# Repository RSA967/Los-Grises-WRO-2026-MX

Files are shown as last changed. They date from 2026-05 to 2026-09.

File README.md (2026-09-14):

# Los-Grises-WRO-2026-MX

Official repository of Team Los Grises for the **Future Engineers - World Robot O1ympiad 2026**.
<div align="center">
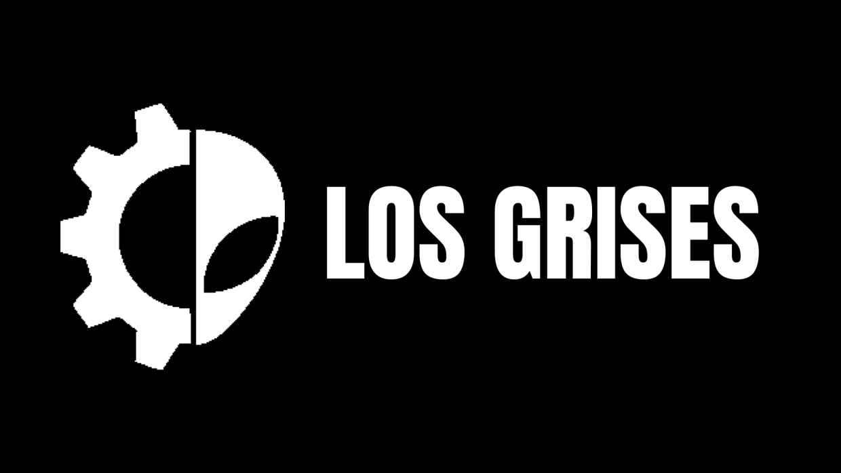
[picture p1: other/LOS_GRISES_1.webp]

</div>

## Robot Overview

Our robot follows a track using a steering servo and a DC drive motor. We use five ultrasonic sensors to measure wall distances, a BNO085 to track rotation, and an encoder to detect movement. For the Obstacle Challenge, an OpenMV camera also finds colored pillars and parking walls.

We have two programs for the ESP32, our main controller. In the **Open Challenge**, the robot follows the corridor, turns at corners and counts three laps before its final positioning maneuver. In the **Obstacle Challenge**, it passes red pillars on the right and green pillars on the left, then searches for the parking area after three laps.

Throughout this guide, motor percentages mean **PWM commands**, and servo angles mean **servo commands**. They are the settings we use to control motion, not measurements of road speed or wheel angle. Our recorded measurements are in [Testing and Calibration](#testing-and-calibration).

<!-- PENDING: confirm that the code, CAD, schematic and photographs correspond to the final competition robot. -->

## Robot Gallery

<table>
<tr>
  <th align="center">Front</th>
  <th align="center">Rear</th>
  <th align="center">Left</th>
</tr>

<tr>
  <td align="center" valign="middle">
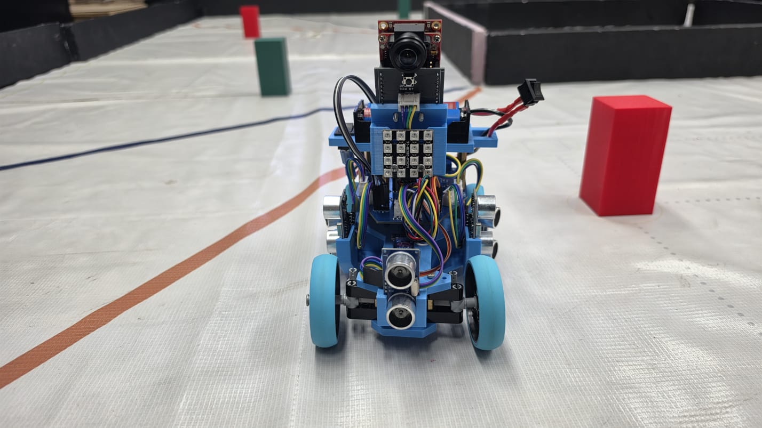
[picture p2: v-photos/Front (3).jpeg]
Robot front view
    
  </td>
  <td align="center" valign="middle">
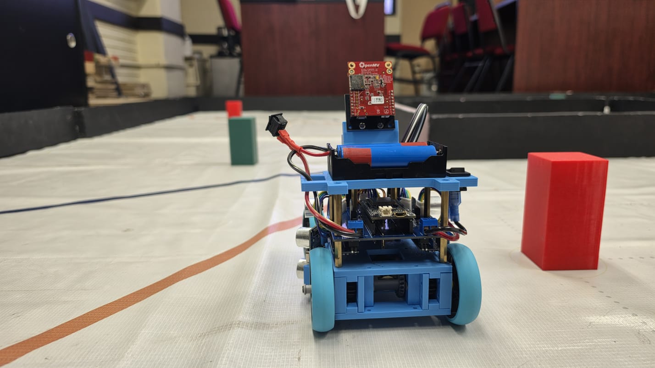
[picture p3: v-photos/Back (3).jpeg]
Robot rear view
    
  </td>
  <td align="center" valign="middle">
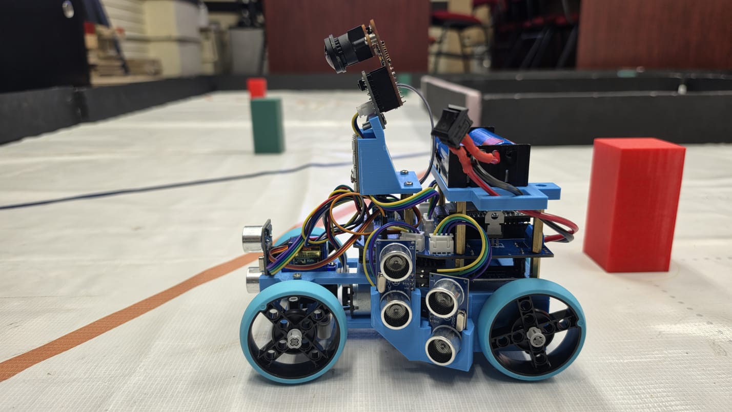
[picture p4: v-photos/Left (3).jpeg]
Robot left view
    
  </td>
</tr>

<tr>
  <th align="center">Right</th>
  <th align="center">Top</th>
  <th align="center">Bottom</th>
</tr>

<tr>
  <td align="center" valign="middle">
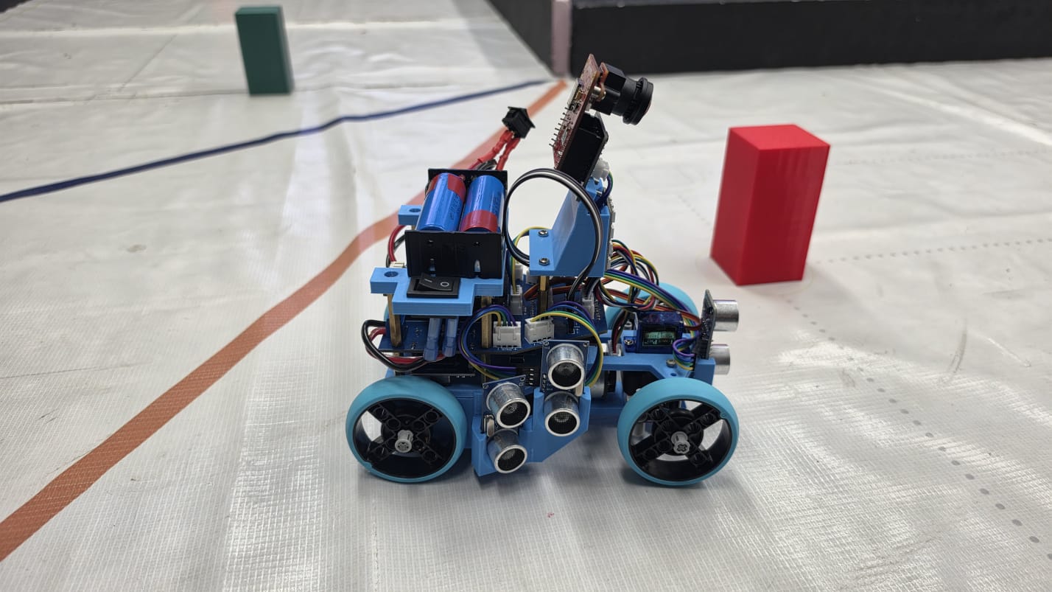
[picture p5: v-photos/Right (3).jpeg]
Robot right view
    
  </td>
  <td align="center" valign="middle">
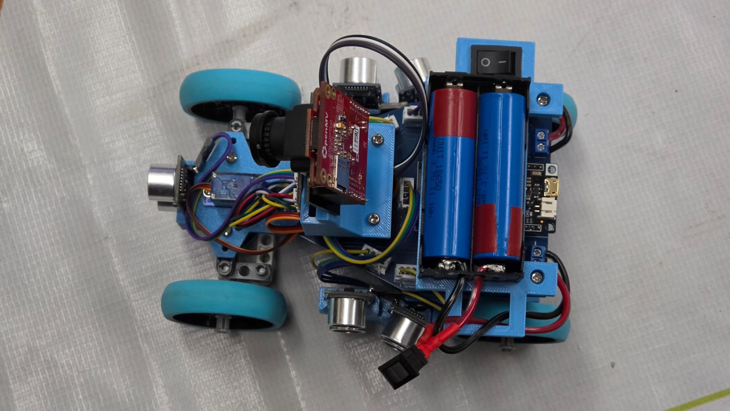
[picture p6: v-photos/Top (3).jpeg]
Robot top view
    
  </td>
  <td align="center" valign="middle">
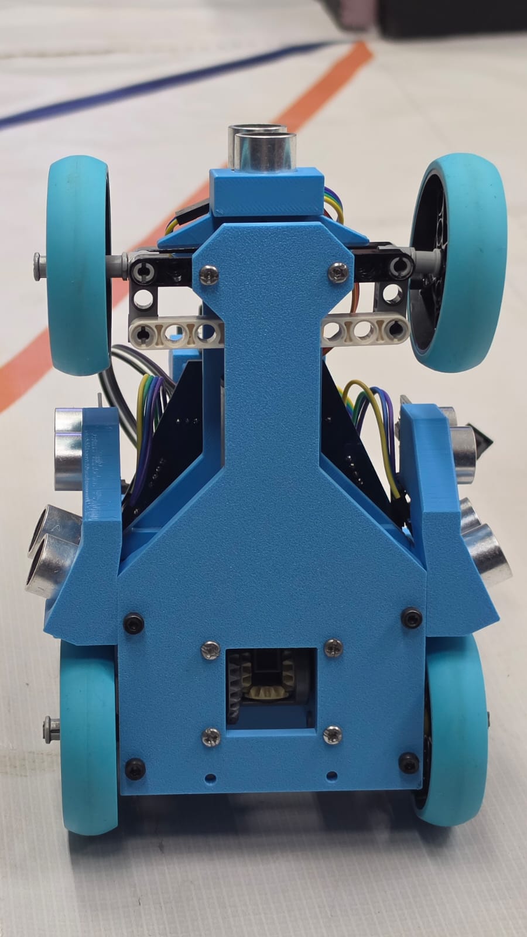
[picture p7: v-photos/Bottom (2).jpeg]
Robot bottom view
    
  </td>
</tr>
</table>

## Challenge Videos

### Open Challenge

<div align="center">

### 🧩 Driving Demonstration

</div>
<!-- PENDING: add a public or unlisted YouTube link showing at least 30 seconds of autonomous Open Challenge driving. -->

### Obstacle Challenge

<div align="center">

### 🧩 Driving Demonstration

</div>

<!-- PENDING: add a public or unlisted YouTube link showing at least 30 seconds of autonomous Obstacle Challenge driving. -->

## Mechanical Design

We control propulsion and steering separately. A DC motor provides drive through the TB6612FNG motor driver, while a servo moves the steering linkage. This lets us reverse the motor without changing how we command the steering. Our component list names a **GM25-370 6V 100RPM motor** and an **SG90 servo**; the voltage and speed in the motor name are part ratings.

The [3D model](https://github.com/RSA967/Los-Grises-WRO-2026-MX/raw/refs/heads/main/models/3D%20design%20of%20the%20robot%E2%80%94open%20in%20Onshape.3mf) contains the upper and lower bodies, a rear support, and left, right and central parts. It includes 24 mesh objects and uses **meters** as its unit. These shapes help show how the body and supports fit into the design.

We center the servo at **90°** and limit normal steering commands to **50–130°**. The challenge programs use different corrections within that range for following walls, turning corners and reversing.

<!-- PENDING: confirm final dimensions and weight; complete the steering-linkage/Ackermann geometry, driven-axle, wheel, transmission and assembly descriptions. -->

## Electronics and Power System

Our [electrical schematic], labelled **WRO 26 INDIA**, shows the FireBeetle ESP32 **DFR0478**, the Nano, camera, IMU and actuator connections. The TB6612FNG uses channel A for the drive motor. The ESP32 sends its speed command through PWM and selects direction through two digital signals.

The power circuit has an 18650 battery input, a switched **VM** branch for the motor, and Mini 560 buck-converter branches labelled **5+** and **3.3**. Separate 7805 regulator branches supply the servo and NeoPixel lighting. The drawing also shows common ground connections, a logic-level converter between 5 V and 3.3 V signal domains, and a **100 nF capacitor** across the motor terminals.

The [connection reference] gives the pin assignments and power-net details. Our [component inventory] includes tools and duplicate parts as well as robot components, so its quantities describe our inventory rather than the number fitted to one robot.

<!-- PENDING: confirm installed quantities and the BNO080/BNO085 module identity; reconcile the battery arrangement, final I2C/power wiring and PCB revision before completing the assembly instructions. -->

## Sensor Architecture

### Five HC-SR04 ultrasonic sensors

We place sensors on both sides and at the front. The side readings help us follow the corridor and finish passing pillars; the front sensor helps us slow down and detect a wall before reversing.

| Sensor | Position | Nano trigger / echo | Use in navigation |
|---|---|---|---|
| S1 | Left, 90° | D2 / D3 | Left corridor distance; red-pillar side confirmation |
| S2 | Left, 25° | D4 / D5 | Left corridor distance, Open corner detection and red-pillar confirmation |
| S3 | Front | D6 / D7 | Corner proximity, slowdown and front-wall escape |
| S4 | Right, 25° | D8 / D9 | Right corridor distance, Open corner detection and green-pillar confirmation |
| S5 | Right, 90° | D10 / D11 | Right corridor distance; green-pillar side confirmation |

The Nano reads **S3 → S1 → S5 → S2 → S4**. We check the front first, then alternate sides and leave a **10 ms delay** after each reading to space out the ultrasonic pulses. Each new distance becomes available immediately.

The Nano sends distances in millimeters over I²C at address **0x08**. The ESP32 requests ten bytes: two for each sensor, in S1-to-S5 order. It requests an update every 20 ms, using the latest reading from each sensor; the sensors are read sequentially, not all at once.

We limit the range to **2,000 mm**. A missing echo is also sent as 2,000 mm, so that value can mean either a clear path beyond the range or no echo. The [Nano program] contains the scan and message format.

### BNO085 and encoder

We use the BNO085's rotation-vector data to calculate **yaw**, the direction the robot is facing, and add up changes in rotation. We reject jumps greater than 90° between samples. This gives us the accumulated rotation used to count laps and guide Open's corner turns.

The encoder has A and B connections to **D5 and D9** on the ESP32. We count rising edges on channel A. In Open, these pulses confirm that the motor has started moving. In Obstacles, we also convert pulses to distance for collision recovery and parking.

The Obstacle program combines distance and heading into an X/Y position estimate. It uses the commanded motor direction for the sign of movement; channel B is not used to decode direction. This estimate does not directly steer the corridor controller.

### Camera and lighting

The **OpenMV H7 Plus** processes the image and sends object information to the ESP32. The Nano handles white NeoPixels on **D12** and receives brightness commands over I²C. Our Nano program is configured for **16 LEDs**.

## Software Architecture

The ESP32 brings the sensor information together and chooses the movement behavior. The Nano handles ultrasonic timing and lighting, while OpenMV handles image processing. This keeps their tasks separate from the main steering and drive logic.

```mermaid
flowchart LR
    US["Five HC-SR04 sensors"] -->|"Trigger / echo"| N["Arduino Nano"]
    N -->|"I2C: five distances"| E["ESP32: main controller"]
    E -->|"I2C: brightness"| N
    N -->|"D12"| LED["NeoPixel lighting"]
    CAM["OpenMV H7 Plus"] -->|"UART: vision data"| E
    E -->|"UART: parking mode"| CAM
    IMU["BNO085"] -->|"I2C: rotation vector"| E
    ENC["Motor encoder"] -->|"Movement pulses"| E
    E -->|"PWM"| SERVO["Steering servo"]
    E -->|"PWM and direction"| DRIVER["TB6612FNG"]
    DRIVER --> MOTOR["DC drive motor"]
```

The camera connections are used by the Obstacle program. Open follows the corridor without reading the camera. Power wiring and level conversion are shown in the schematic above.

| Controller / purpose | Source file |
|---|---|
| ESP32, Open Challenge | [ESP32_Open_Giro_90.ino](https://github.com/RSA967/Los-Grises-WRO-2026-MX/blob/main/src/ESP32_Open_Giro_90.ino) |
| ESP32, Obstacle Challenge | [ESP32_Obstaculos_V2.ino](https://github.com/RSA967/Los-Grises-WRO-2026-MX/blob/main/src/ESP32_Obstaculos_V2.ino) |
| Arduino Nano, sensors and lights | [Nano_Sensores_I2C__1_.ino](https://github.com/RSA967/Los-Grises-WRO-2026-MX/blob/main/src/Nano_Sensores_I2C__1_.ino) |
| OpenMV, vision | [color_corner.py](https://github.com/RSA967/Los-Grises-WRO-2026-MX/blob/main/src/color_corner.py) |

We load one challenge sketch on the ESP32 at a time. The two sketches stay in separate folders; they are not combined into a single program.

## Open Challenge Strategy

Our Open sequence is:

**Start → confirm movement → follow the corridor → detect and turn a corner → update the lap count → repeat → final positioning.**

### Starting and following the corridor

We begin with a **45% motor command** and wait for **four encoder pulses within a 600 ms detection window**. Once movement is confirmed, we start the round timer and a **five-second acceleration ramp**. This keeps the start tied to actual movement instead of just switching on the electronics.

To follow the corridor, we compare the left and right distance sums:

`error = (S1 + S2) - (S4 + S5)`

A **PID controller** turns that error into a steering correction. The proportional term responds to the current error, the integral term builds up while an error remains, and the derivative term responds to how quickly it changes. Our Open gains are **Kp = 0.04, Ki = 0.001, Kd = 0.003**. We limit the integral contribution and filter the derivative so that they do not produce excessive corrections.

Steering starts with a reduced proportional gain. As a front or side wall gets closer, we increase the response and reduce the motor target. The normal target is **100%**, reducing toward **60%** near walls. Front-distance slowdown grows between **600 and 200 mm**. When front and side protection both request a slowdown, we use the lower target.

### Detecting and turning corners

We look for a change from a nearby wall to an opening at S2 or S4. A reading of **800 mm or less** arms that side. A later reading of **at least 1,250 mm**, while S3 is still at **800 mm or less**, becomes a corner candidate. We require three confirming polls before turning.

During the turn, we use the BNO085 to track a **90° change in rotation**, with a 2° completion tolerance. The steering correction is **35°** and the motor command is **55%**. We then center the servo briefly before returning to corridor PID. Once a course direction has been chosen, later corner detections follow that direction.

If a turn has not finished after **2.5 seconds**, or valid heading is lost during the turn, the robot stops rather than continuing the turn indefinitely.

### Front-wall protection and recovery

If **S3 reaches 150 mm or less**, we cut drive, center the steering and brake before reversing at **45%**. We keep steering centered during this escape and resume forward control when S3 reaches **250 mm**. If reverse motion does not clear the wall within **2.5 seconds**, the robot stops and waits.

The general distance-data timeout is **250 ms**. Heading-loss behavior depends on the current maneuver: a 90° turn and final heading adjustment have their own stop conditions. The current setting allows ordinary corridor movement without heading, so an IMU failure is not a universal motor stop.

### Counting laps and final positioning

After encoder-confirmed startup, we accumulate the BNO085's rotation. Each 360° contributes one lap; at **1,080° of absolute accumulated turn**, we begin final positioning. This is our internal lap counter, based on rotation rather than detection of every field section.

We keep normal control for **500 ms of effective commanded forward motion**. Braking and reverse-escape pauses do not count toward this interval. Then, if S3 is below **1,000 mm**, we reverse at **35%** while correcting heading toward ±1,080°. The adjustment ends at **1,100 mm** of front clearance, after a **five-second limit**, or on the relevant sensor failure. If no adjustment is needed, the robot stops directly.

## Obstacle Challenge Strategy

For this challenge, we follow the corridor until the camera finds a pillar. We guide the robot past it on the correct side, use the side sensors to finish the pass, and return to corridor control. After three accumulated laps, we switch to searching for the parking area.

### Passing on the correct side

- **Red pillar, ID 5:** pass on the right, leaving the pillar on our left.
- **Green pillar, ID 3:** pass on the left, leaving the pillar on our right.

We use corridor PID between pillars, with **Kp = 0.12, Ki = 0.0015, Kd = 0.006**. The normal motor target is **70%**, reducing toward **50%** near corners. The IMU counts rotation and supports the position estimate and parking-side choice; it does not directly steer this corridor PID.

### Camera control and pillar lock

When the camera finds a valid target, we **lock its color ID**. This keeps a passing maneuver focused on one pillar instead of switching targets with every image. The upper image region guides the approach. In the lower region, we increase the passing offset as the pillar appears closer to the bottom of the image.

When the robot gets very close, the pillar can leave the camera's view. After the locked pillar reaches the low ROI, we use the side ultrasonics to confirm it alongside the robot: **S1/S2 for red**, and **S4/S5 for green**. A distance of **300 mm or less** in two polls starts the final part of the pass, with a **20° wrap correction** and **35% motor target**.

We release the lock after both sensors on that side report at least **360 mm**, with repeated confirmation and a short clear hold. The wrap also has a time limit, because a wall beside the robot might never give a clear reading. If the old target disappears and a new color is repeatedly detected, the lock can switch to the new pillar.

We return steering gradually to the corridor target, at up to **45° per second**. When a front wall is close, corridor control takes over immediately so that a smooth transition does not delay a needed turn.

### Wall protection and collision recovery

While the camera is steering, a side-wall limiter reduces only the correction that points **toward** a close wall. It works between **300 and 130 mm**, cancelling steering toward that side at 130 mm and limiting the motor target to **45%**. This protects wall clearance, but also leaves less room to go around a pillar.

The front guard adds more steering correction when a pillar is close to a front wall. If S3 reaches **150 mm**, front-wall escape takes priority: we brake, center the servo and reverse until there is **250 mm** of clearance or the escape times out.

We also check whether the locked pillar's image enters the collision region. After **two confirming frames**, we brake and reverse **100 mm at 30%**, using encoder pulses to measure that distance. If the distance is not reached within **1.5 seconds**, we stop anyway. We wait for **three clear frames** before another attempt. This collision indication comes from the camera, not a contact switch.

During forward navigation, wall escape has priority over pillar tracking, followed by collision recovery and the normal camera/corridor behaviors. Parking entry uses its own sequence and limits, described below.

If camera data stops arriving for **500 ms** after communication has started, we release the pillar lock and return toward corridor control. Wall following can continue, but without current vision we cannot rely on the pillar-passing strategy.

## Computer Vision

We use OpenMV to find **red and green pillars**, **parking walls** and a small central sample of the black wall. It processes **320 × 240 RGB565 images** and sends detections to the ESP32 rather than sending full images.

### Color and shape

We find connected color regions, called **blobs**, using LAB thresholds. L represents lightness; A and B represent color axes. These are our active pillar ranges:

| Color | L min / max | A min / max | B min / max |
|---|---|---|---|
| Red | 20 / 55 | 31 / 71 | −19 / 43 |
| Green | 32 / 68 | −128 / −16 | −128 / 127 |

Color alone is not enough. Floor markings can also enter these ranges, so we check shape and how much of the bounding box is filled. A pillar must be taller than it is wide, with a height/width ratio of at least **1.20**, and fill at least **60%** of its box. We also check size and rotation.

Red and magenta overlapped under artificial light, so we use the red-range candidates for parking walls too, then separate them by shape. A wall must be wide, with width/height of at least **1.30**. We reject candidates cut by the top of the parking search region because a cropped pillar can look short and wide. The separate magenta thresholds are not active in this detection path.

### Regions of interest and object position

A **region of interest (ROI)** tells us which part of the image to use for a particular task.

| Region | `(x, y, width, height)` | Purpose |
|---|---|---|
| High | `(90, 100, 140, 40)` | Guide the approach to a pillar |
| Low | `(0, 140, 320, 100)` | Guide the close pass |
| Collision | `(120, 200, 80, 15)` | Check whether the selected reference corner enters the collision zone |
| Parking search | `(0, 70, 320, 170)` | Find wide wall shapes |

We track the **bottom-left corner of green pillars** and the **bottom-right corner of red pillars**. We normalize X to **−100…100**, while Y stays in pixels. Using the same reference corner in both high and low regions keeps the coordinate meaning consistent during the approach. These are image positions, not measured distances in millimeters.

If both colors are present, the camera selects the larger-area candidate, choosing green on a tie. The small central black-wall sample is reported for display; we do not use it to trigger turns.

### Communication and lighting

The camera sends ten comma-separated integers and a newline over **UART at 19,200 baud, 8N1**:

```text
ID,X,Y,AREA,ROI,COLLISION,BLACK_WALL,PARKING_VISIBLE,PARKING_X,PARKING_AREA
```

The ESP32 can send `P,1` or `P,0` to control parking detection. We currently keep detection enabled throughout the run, while the driving sequence waits until three laps to begin parking. The optional path-preview telemetry and overlay are disabled.

At camera startup, we allow a short automatic adjustment, then lock gain and white balance and use **30,000 µs exposure**. In Obstacles, near, far and parking brightness are all **50%**, keeping the light target the same as the robot changes tasks. Open starts with a 0% base and uses a 20% corner indicator.

## Parking Strategy

After three accumulated laps, we search for the parking walls, move alongside the gap and reverse into it in two stages. We use a **state machine** so that each stage has a clear job and a condition for moving to the next one.

```mermaid
stateDiagram-v2
    [*] --> SEARCH: three laps
    SEARCH --> PASSING: wall visible or already passed
    PASSING --> ALIGNING: two walls passed
    ALIGNING --> BRAKING: distance or side clearance or phase timeout
    BRAKING --> REVERSE_TURN: 250 ms
    REVERSE_TURN --> REVERSE_STRAIGHT: 240 mm or phase timeout
    REVERSE_STRAIGHT --> DONE: 150 mm or phase timeout
    DONE --> [*]
```

- **SEARCH:** follow the corridor with a **50% speed cap** and a **10° steering bias** toward the parking side. The bias brings us closer to the side where we are looking for the gap.
- **PASSING:** reduce the cap to **45%** and count two walls. We require repeated visible and absent frames so that one flickering detection does not count as a wall passed.
- **ALIGNING:** advance **260 mm by encoder**, or until the side sensors confirm at least **300 mm** of clearance. A phase timeout also ends this advance, but we only continue into reverse if the parking side is known.
- **BRAKING:** stop for **250 ms** and preposition the steering.
- **REVERSE_TURN:** reverse at **32%**, using a **34° steering correction** with its sign chosen for the parking side, for **240 mm**.
- **REVERSE_STRAIGHT:** countersteer with a **26° correction**, still at **32%**, for **150 mm** to straighten the robot. The servo is not centered during this stage.
- **DONE:** stop the motor and center steering. The robot stays stopped.

At the start of parking, accumulated yaw normally selects the side: positive rotation is configured as counterclockwise and selects the right; negative selects the left. Camera X supplies a side only if one has not already been assigned. While parking, camera messages count walls without starting new pillar-lock or visual-collision actions.

Each reverse stage has a **six-second limit** as an alternative to its distance target. The whole sequence has a **70-second limit**, and **1.5 seconds without Nano data** aborts it. We have no rear-distance sensor, so we bound reverse motion with encoder distance and time. The ordinary 250 ms distance timeout is replaced by the parking timeout, and front-wall escape is suppressed during braking and reverse entry.

Reaching `DONE` means that the movement sequence ended, which can also happen after a phase timeout. It does not measure whether the robot is fully inside the bay and parallel to the wall; those are the checks needed when observing a parking attempt.

## Engineering Decisions and Improvements

Our control decisions connect the sensing and movement tasks. A smoother steering change is not always the best choice near a wall, and a newer camera reading can be more useful than processing every queued frame. The following choices explain how we handle these situations. More detail is in our [Engineering Journal]

### Giving ultrasonic readings time and keeping I²C responsive

We read the ultrasonics sequentially and alternate sides to space out their pulses. Publishing each result immediately lets the ESP32 use it without waiting for the other four sensors. The trade-off is that the five distances come from slightly different times.

For Obstacles, we reduced I²C from **100 to 50 kHz** to give the signals more settling time in the presence of electrical noise. Open remains at 100 kHz. We also limit I²C waiting and reinitialize the bus when the Nano stops responding. Slowing communication and retrying it are separate measures: one changes normal timing, while the other addresses a stalled connection.

### Staying with a pillar without following an old target

The pillar lock solves one problem but can create another: holding the old color too long can keep steering toward a pillar we have already passed. We combine the camera-to-ultrasonic handoff with side-clearance checks and time limits, and allow a repeatedly detected new color to replace a stale target. This balances finishing one pass with responding to the next pillar.

### Balancing smooth steering and wall clearance

We use a gradual return to corridor PID on clear sections, but allow an immediate return near a front wall. Smooth steering is useful until it delays a turn that needs to happen now.

A fixed **8°** front-guard correction was too small in a corner, so we changed it to grow from **8° to 20°** as the front distance decreases. The side-wall limiter handles a separate compromise: keeping farther from the wall can leave less clearance around the pillar.

### Tying motion to encoder pulses

We use encoder pulses to confirm startup before beginning the acceleration ramp. In Obstacles, we also cap startup output at the requested target: a behavior asking for 30% should not receive the 45% startup command.

For collision recovery, we reverse by a measured pulse count corresponding to **100 mm** and add a time limit in case the distance is not reached. The same pulse-to-distance conversion supports parking. This connects our encoder calibration to the maneuvers that need distance information.

### Recovering sensors and discarding old images

An IMU that fails to initialize should not be ignored for the rest of the run. The Obstacle program retries before and after the round timer starts, with longer intervals after startup because initialization can interrupt normal control. It also reinitializes after a prolonged loss of rotation data.

Camera messages can queue up while the ESP32 is busy. Steering from an old image would point toward an outdated pillar position, so we discard excess backlog and process a limited number of complete messages per loop. This leaves time for distance readings and steering updates, at the cost of skipping some camera frames.

### Using shape and steady lighting

When red and magenta overlapped under artificial light, we separated tall pillars from wide walls instead of relying only on color. We also lowered the wall width/height threshold from **1.50 to 1.30** because an oblique wall could fall close to the old limit.

An exposure of **10,000 µs** made the image too dark, so we use **30,000 µs**. We keep the same 50% lighting target through obstacle driving and parking, avoiding a light-target change just when the camera begins a different task.

## Testing and Calibration

### Encoder distance calibration

Our encoder calibration notes record two trials over one meter:

| Trial / calculation | Result |
|---|---|
| Test 1, 1 meter | **3,870 pulses** |
| Test 2, 1 meter | **3,988 pulses** |
| Average | **3,929 pulses/m** |
| Conversion | `1000.0 / 3929.0` ≈ **0.2545 mm/pulse** |

We multiply the pulse count by this conversion in the Obstacle program to calculate collision-recovery and parking distances. It also feeds the position estimate. Open uses pulses to confirm startup, without applying this distance conversion.

### Camera observations

Our vision notes describe parking-wall width/height ratios of approximately **2.0 front-on** and **1.5 at an oblique angle**. This explains the change to a 1.30 wall threshold. They also compare a solid pillar filling roughly **85% or more** of its box with a diagonal floor marking around **45%**, which supports using a density filter. These are approximate observations, not a detection-accuracy score.

PID gains, LAB thresholds and maneuver limits are settings, not experimental results. The [calibration record](tests/calibration.md) keeps the measurement notes and the separate track-time estimate together, with their context.

<!-- PENDING: add final-version Open and Obstacle run records or videos, including observed parking containment, alignment and contact with bay markers. -->

## CAD, PCB and Manufacturing

Use these files to inspect the mechanical parts, follow the connections and understand the board layout:

| Asset | Use |
|---|---|
| [Part Studio 1.3mf](https://github.com/RSA967/Los-Grises-WRO-2026-MX/raw/refs/heads/main/models/3D%20design%20of%20the%20robot%E2%80%94open%20in%20Onshape.3mf) | View the 24 mesh objects for the body and supports. Check that the viewer respects the meter units. |
| [Electrical schematic](https://github.com/RSA967/Los-Grises-WRO-2026-MX/blob/main/models/Layout%20of%20the%20Printed%20Circuit%20Board%20(PCB)%20Components.jpeg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) | Follow controller, sensor, actuator and power connections. |
| [PCB layout](https://github.com/RSA967/Los-Grises-WRO-2026-MX/blob/main/models/(PCB).jpeg?raw=true) | View tracks, connectors and component footprints. |
| [Fabricated PCB photo](https://github.com/RSA967/Los-Grises-WRO-2026-MX/blob/main/models/Layout%20of%20the%20Printed%20Circuit%20Board%20(PCB)%20Components.jpeg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) | See the unpopulated board before components are fitted. |
| [Component inventory](https://github.com/RSA967/Los-Grises-WRO-2026-MX/raw/refs/heads/main/models/Tabla_de_componentes_robotica.docx) | Identify part names and view component photographs. |

The PCB files here are images for reading the layout and connections. Manufacturing a matching board requires the editable design and fabrication outputs. The 3MF contains part meshes rather than a parametric CAD history.

<div align="center">
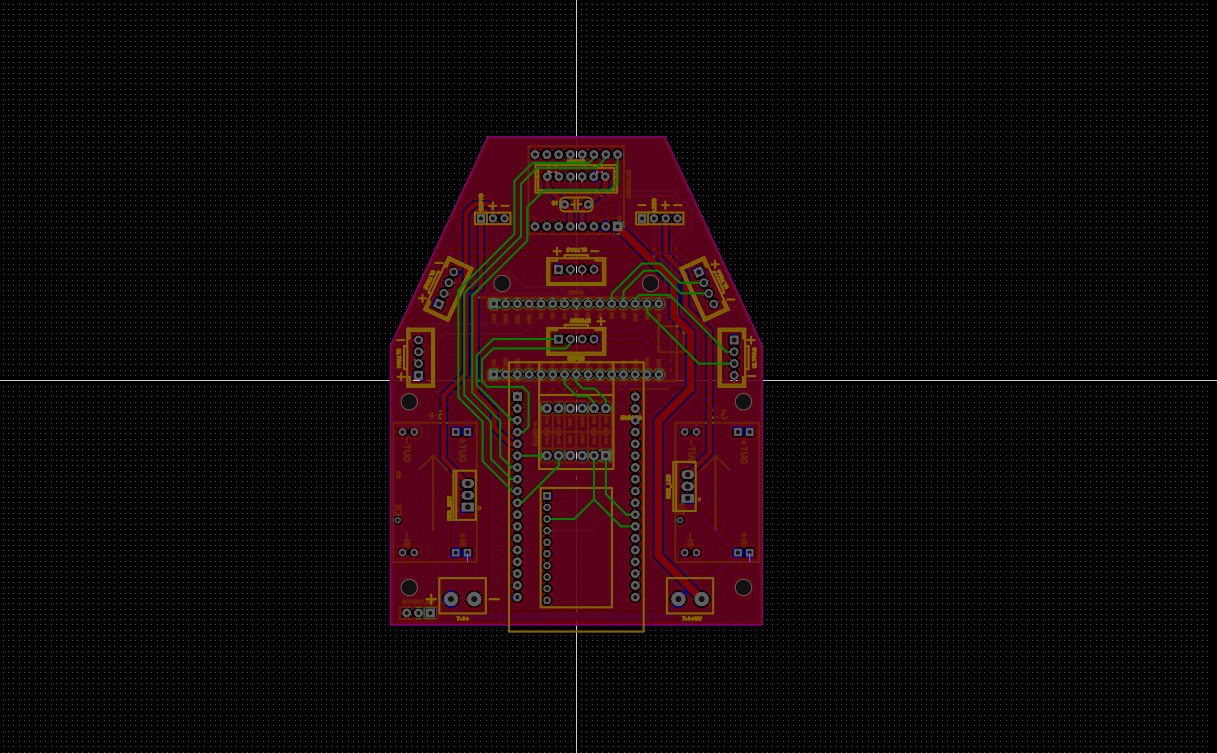
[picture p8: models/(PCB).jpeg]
</div>

<div align="center">
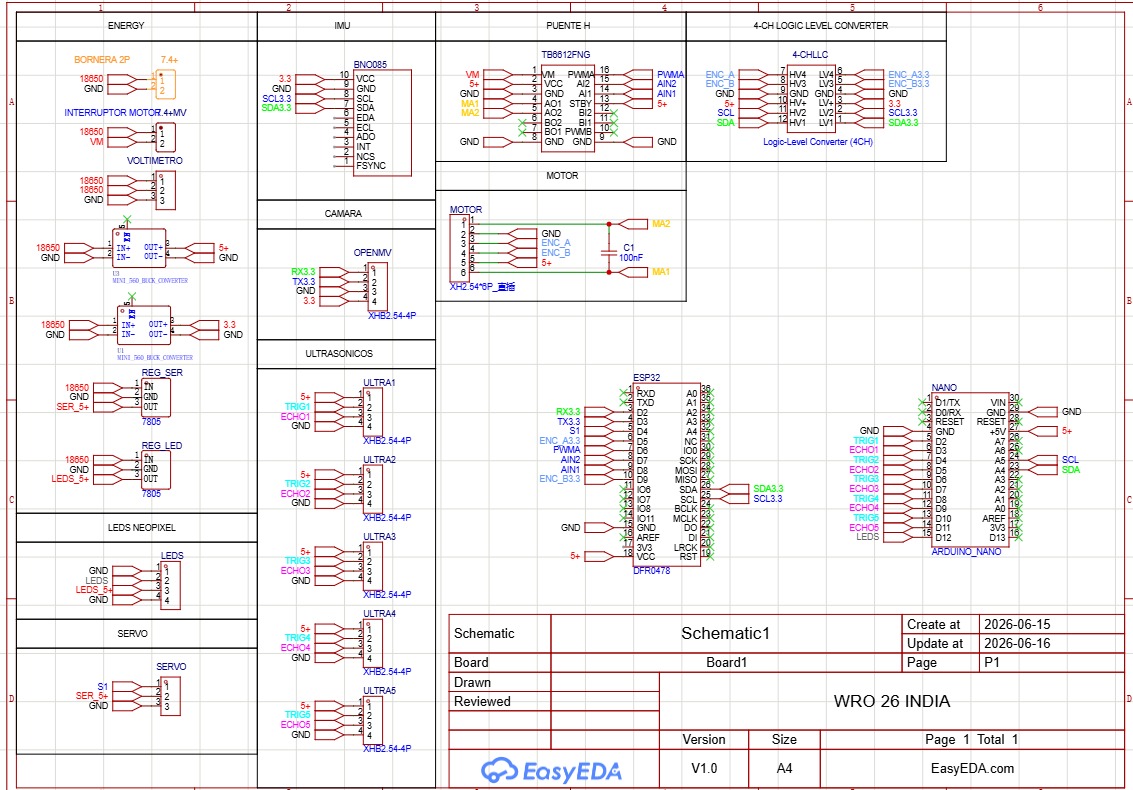
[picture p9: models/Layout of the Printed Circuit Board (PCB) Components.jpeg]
</div>

<!-- PENDING: add the PCB fabrication outputs and assembly instructions needed to reproduce the final mechanical and electronic build. -->

## Repository Structure

The main robot files and technical guides are organized as follows:

```text
README.md
code/
  ESP32_Open_Giro_90/ESP32_Open_Giro_90.ino
  ESP32_Obstaculos_V2/ESP32_Obstaculos_V2.ino
  Nano_Sensores_I2C__1_/Nano_Sensores_I2C__1_.ino
  openmv/color_corner.py
cad/Part Studio 1.3mf
pcb/layout.jpg
wiring/schematic.jpg
images/pcb-fabricated.jpeg
tests/calibration.md
docs/
  electronics.md
  engineering-journal.md
  components-original.docx
  references/
    future-engineers-2026-rules-es.pdf
    future-engineers-2026-rubric-es.pdf
```

## How to Reproduce the Robot

### Hardware and connections

Start with the [3D model], [schematic], [component inventory] and [pin reference]. The model shows part geometry; the pin reference covers the five sensor pairs, motor driver, servo, encoder, I²C and camera UART. The inventory also contains duplicate parts and workshop tools.

### Programs and dependencies

Open the `.ino` file inside its matching sketch folder and select the challenge program for the ESP32. Upload the Nano sketch to the Nano separately. The ESP32 pin aliases follow the **FireBeetle DFR0478** layout, so the board definition matters when resolving names such as `D5` and `D6`.

The ESP32 sketches use `Wire`, `Adafruit_BNO08x`, `WiFi`, `WebServer` and `esp_arduino_version`. The Nano sketch uses `Wire` and `Adafruit_NeoPixel`. The ESP32 PWM setup contains separate branches for board-package versions below 3 and versions 3 or above.

Run `color_corner.py` on the OpenMV camera. It uses `sensor`, `time`, `micropython`, `machine.UART` and `binascii`/`ubinascii`, so it needs the OpenMV environment rather than desktop Python. Camera UART3 runs at **19,200 baud**; the ESP32 side uses **RX GPIO25 and TX GPIO26**.

### Preparing and checking the system

Before a run, use the sensor layout and calibration values in this guide to check the steering center, encoder conversion and camera settings against the hardware. The Nano should respond at **0x08** with ten bytes, and OpenMV should send the ten-field message described above.

The ESP32 serial monitor runs at **115,200 baud** and reports distances, movement states and faults. In Open, the electronics can stay powered while the motor-power switch is open; movement confirmation starts when encoder pulses arrive.

The dashboards are enabled in the current sketches for testing. For competition rounds, Wi-Fi must be disabled as required by the rules. The code has a dashboard-off setting that switches off Wi-Fi; the competition configuration still needs to be selected and checked before a run.

<!-- PENDING: record the tested board definitions, library/OpenMV firmware versions, exact upload and persistent startup steps, and confirm the final competition configuration with wireless disabled. -->
<!-- PENDING: confirm the submitted repository URL, required historical commits, event deadline and final version notes before submission. -->

|COMPONENT| DESCRIPTION | IMAGE | PURCHASE LINK|
|---|---|---|---|
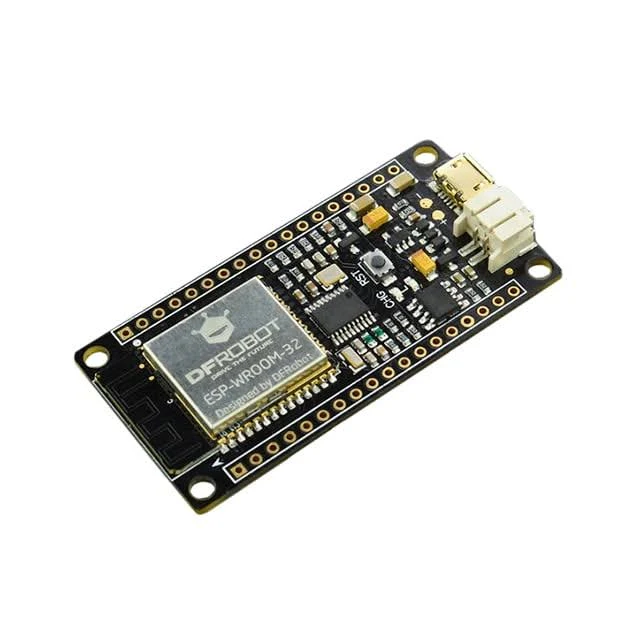
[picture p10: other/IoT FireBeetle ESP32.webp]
|IoT FireBeetle ESP32|FireBeetle ESP32: IoT board with Wi-Fi, Bluetooth, a lithium battery charging chip, and ultra-low power consumption (10 µA in standby mode).|  |[Buy here](https://www.amazon.com.mx/UEYGHEP-FireBeetle-Development-Bluetooth-habilitado/dp/B0GFDXH1XS)|
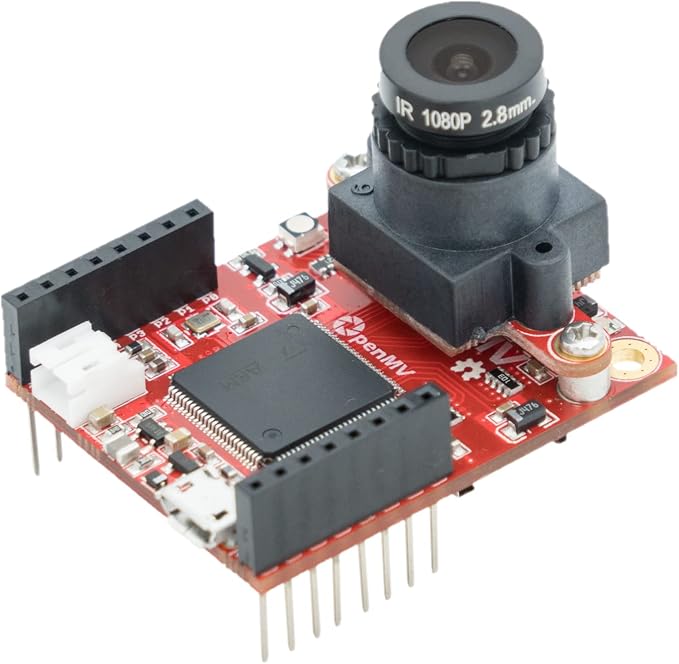
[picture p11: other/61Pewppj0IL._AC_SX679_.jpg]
|Genuine OpenMV CAM H7 Plus / OpenMV4 CAM H7 Plus, 5MP|OpenMV H7 Plus: A 5 MP camera programmable in MicroPython for computer vision and AI (TensorFlow Lite), featuring a 480 MHz processor, 32 MB of SDRAM, and UART/I2C/SPI outputs for robotics.|  |[Buy here](https://www.amazon.com.mx/OpenMV-SingTown-Processing-Robotics-Detection/dp/B09WYQR6XH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)|
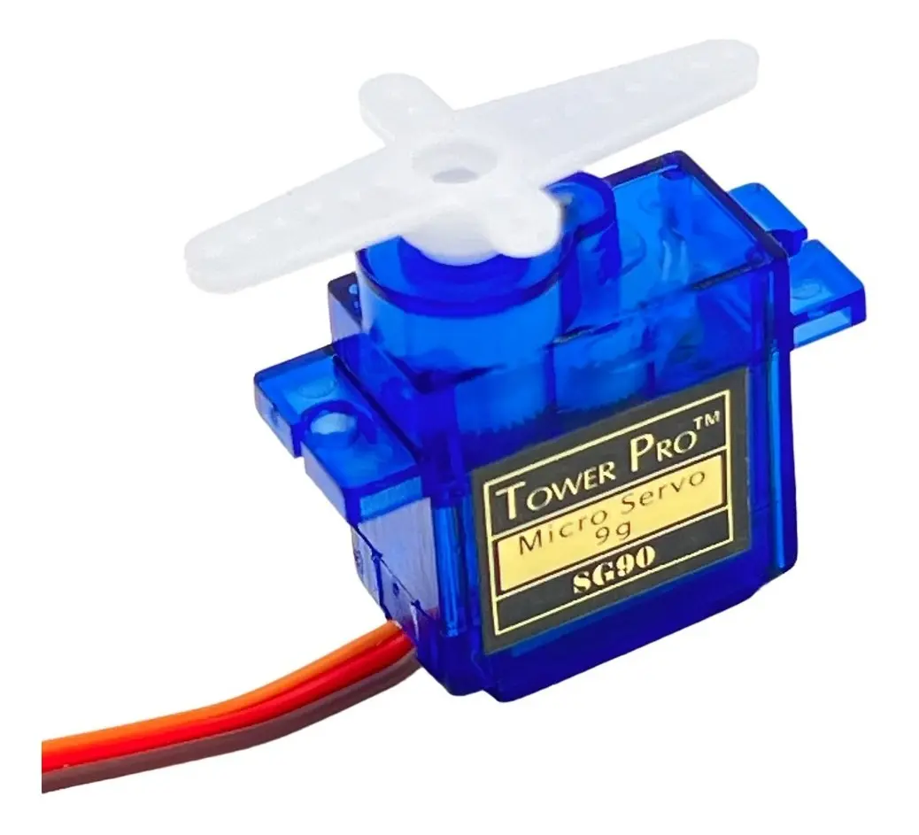
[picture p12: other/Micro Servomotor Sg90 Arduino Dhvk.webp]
|Micro SG90 9G Servomotor|SG90 Servo (9g): Compact, PWM-controlled actuator with a 180^\circ range, 1.8 kg·cm of torque at 5V, and plastic gears—ideal for lightweight robotics.|  |[Buy here](https://www.mercadolibre.com.mx/micro-servomotor-sg90-arduino-dhvk/p/MLM2072764647)|
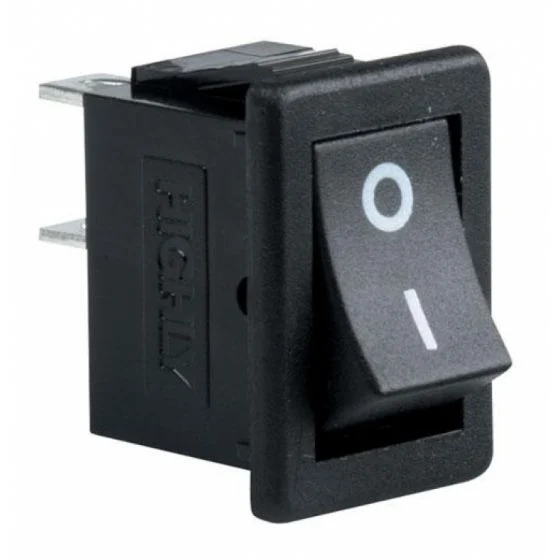
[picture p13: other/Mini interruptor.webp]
|Mini Switch|Compact mechanical on/off (ON/OFF) or circuit-switching switch, ideal for controlling power or signals in electronics and robotics projects.|  |[Buy here](https://www.steren.com.mx/switch-miniatura-de-balancin-de-1-polo-1-tiro-2-posiciones.html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)|
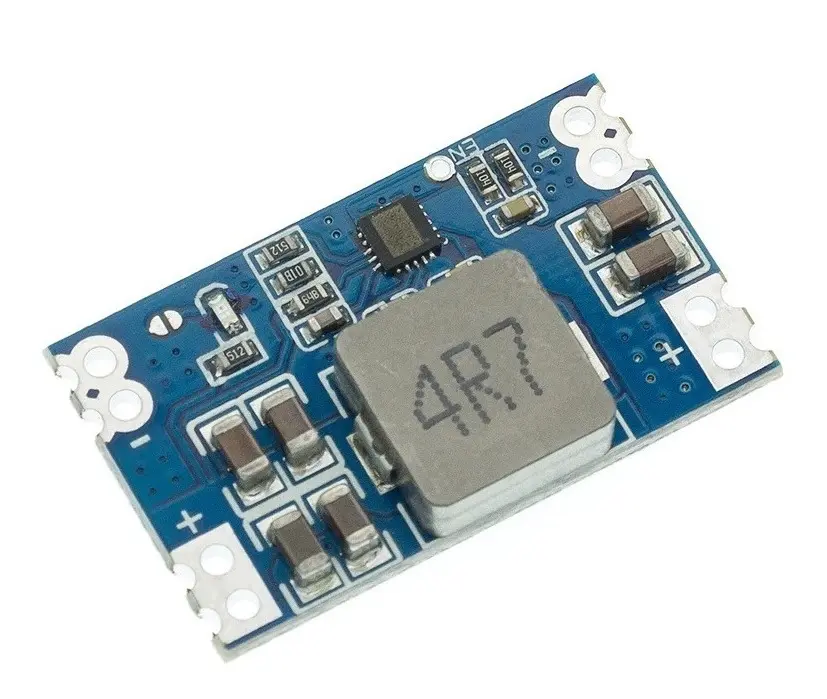
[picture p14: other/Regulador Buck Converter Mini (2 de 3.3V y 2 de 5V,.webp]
|Mini Buck Converter (2 x 3.3V and 2 x 5V, |A compact step-down voltage regulator module that converts higher input voltages (6V–20V) into two 3.3V and two 5V fixed outputs simultaneously to power microcontrollers and sensors.|  |[Buy here](https://www.mercadolibre.com.mx/mini560-regulador-step-down-buck-520v-a-33v-5a/up/MLMU801699768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)|
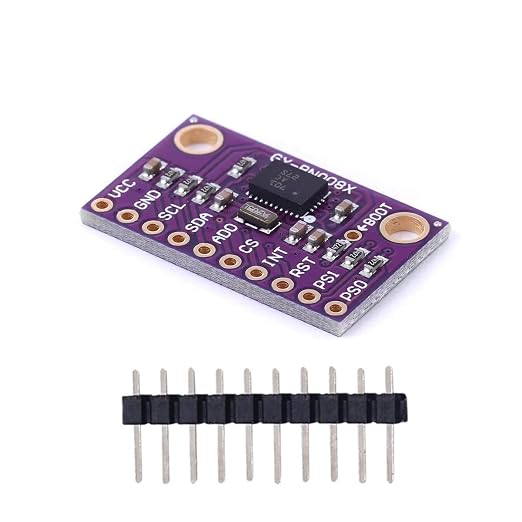
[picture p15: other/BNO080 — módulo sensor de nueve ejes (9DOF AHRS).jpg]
|BNO080 — Nine-Axis Sensor Module (9DOF AHRS)|Nine-axis sensor module combining a 3-axis accelerometer, 3-axis gyroscope, and 3-axis magnetometer with an onboard ARM Cortex-M0+ running Hillcrest's SH-2 firmware. It performs onboard sensor fusion to output precise 3D orientation (quaternions, Euler angles) over I2C, SPI, or UART without burdening the main microcontroller.|  |[Buy here](https://www.amazon.com.mx/MerciL-BNO080-BNO085-Aceler%C3%B3metro-Magnet%C3%B3metro/dp/B0D676S54D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)|
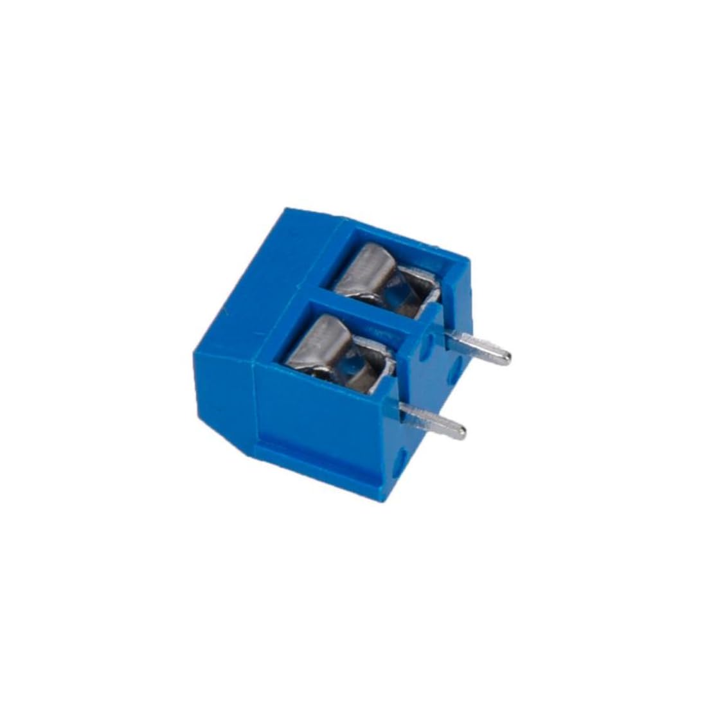
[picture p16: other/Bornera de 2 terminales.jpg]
|2-terminal terminal block|A screw or push-in connector module that allows secure, detachable wiring connections between power sources or components and a circuit board without soldering.|  |[Buy here](https://www.amazon.com.mx/BORNERA-CULCA-CLEMA-PAQUETE-PIEZAS/dp/B08MLGXP52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)|
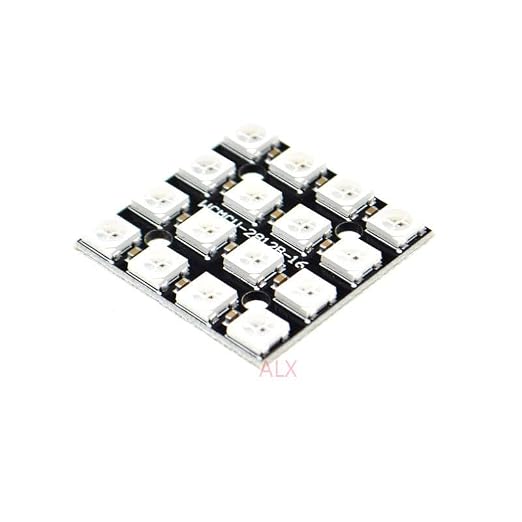
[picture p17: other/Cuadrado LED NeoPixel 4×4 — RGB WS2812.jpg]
|4×4 NeoPixel LED Square — RGB WS2812|A compact matrix of 16 individually addressable RGB LEDs that can display over 16 million colors using a single microcontroller data pin.|  |[Buy here](https://www.amazon.com.mx/bits-WS2812B-5050-M%C3%B3dulo-color/dp/B09T5XJP69)|
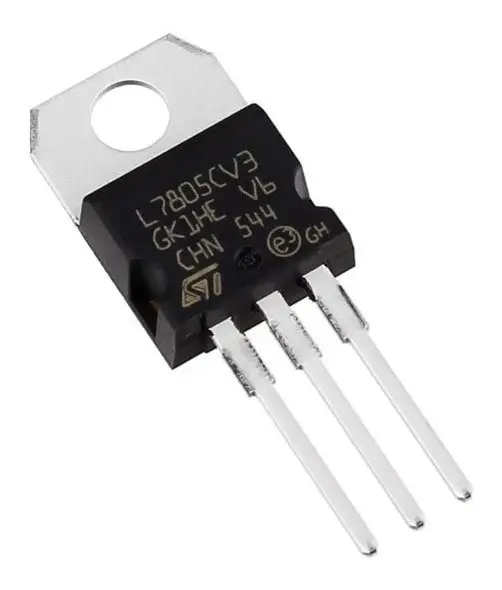
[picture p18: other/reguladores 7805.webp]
|7805 regulators|A linear regulator that steps down higher DC input voltages (7V–35V) to a stable, fixed 5V output at up to 1.5A.|  |[Buy here](https://www.mercadolibre.com.mx/50-pzs--7805--l7805-regulador-voltaje-5-volts/up/MLMU974457952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)|
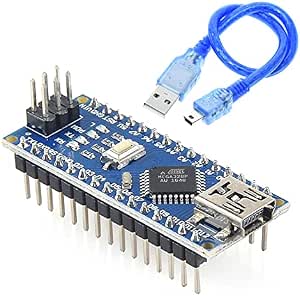
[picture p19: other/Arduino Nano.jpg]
OpenMV Cam[ H7 Plus
|Arduino Nano|A compact, breadboard-friendly microcontroller board based on the ATmega328P, running at 16 MHz with 32 KB Flash memory and an integrated USB port for easy programming.|  |[Buy here](https://www.amazon.com.mx/UNIT-ELECTRONICS-Cable-Compatible-Arduino/dp/B09MRFHR9C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)|
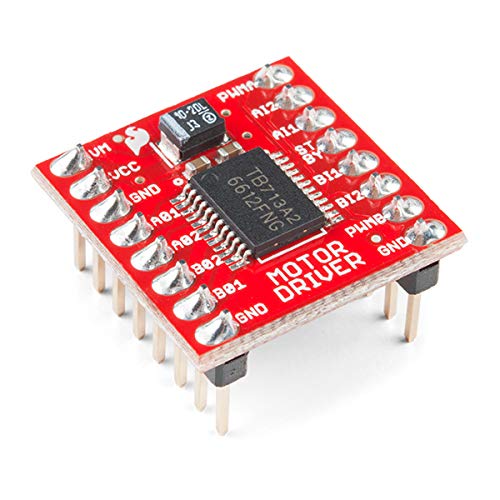
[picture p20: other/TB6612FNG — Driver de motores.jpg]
|TB6612FNG — Motor Driver|A dual H-bridge motor driver IC that can independently control speed (via PWM) and direction for two DC motors (up to 1.2A continuous per channel, 3.2A peak) or one stepper motor, offering high efficiency over traditional L298N drivers.|  |[Buy here](https://www.amazon.com.mx/SparkFun-TB6612FNG-driver-motor-cabezales/dp/B07PV1S8HX)|
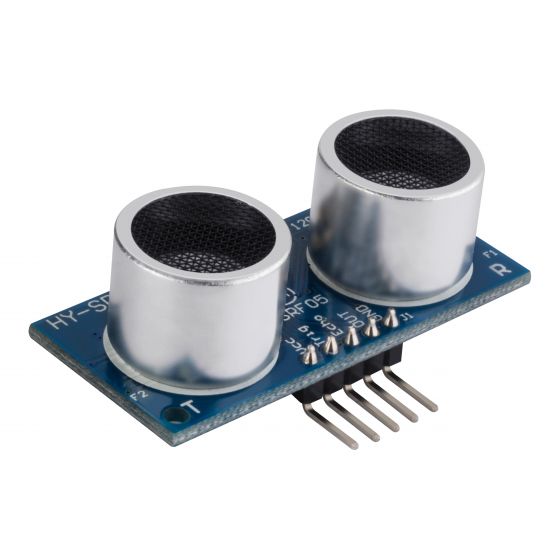
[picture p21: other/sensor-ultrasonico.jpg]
|HC-SR04 — Ultrasonic Sensors|A non-contact distance measurement module using 40 kHz ultrasound waves to measure distances from 2 cm to 400 cm with ~3 mm accuracy.|  |[Buy here](https://www.steren.com.mx/sensor-ultrasonico.html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)|
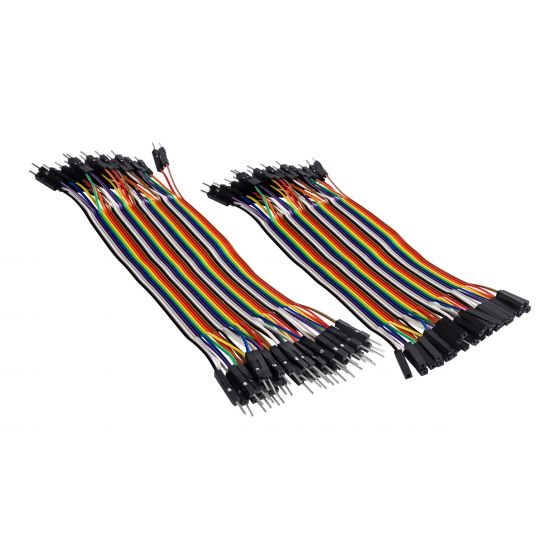
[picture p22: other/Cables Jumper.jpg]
|Bridge Cables|Flexible insulated wires with pin connectors (male-to-male, female-to-female, or male-to-female) used to make quick, temporary electrical connections on breadboards, sensors, and development boards without soldering.|  |[Buy here](https://www.steren.com.mx/juego-de-80-cables-de-15-cm-tipo-dupont.html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)|
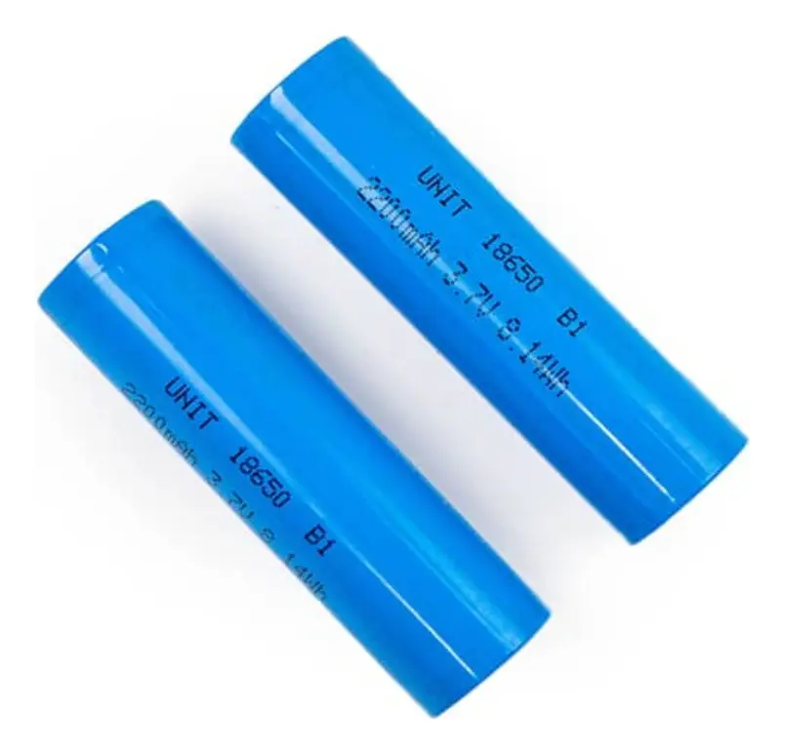
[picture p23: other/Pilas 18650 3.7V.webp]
|3.7V 18650 Batteries|A standard rechargeable lithium-ion cell (18 mm x 65 mm) providing a nominal voltage of 3.7V, widely used in robotics and portable devices for its high energy density and capacity.|  |[Buy here](https://www.mercadolibre.com.mx/2-piezas-pila-18650-37v-2200mah/up/MLMU479366103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)|
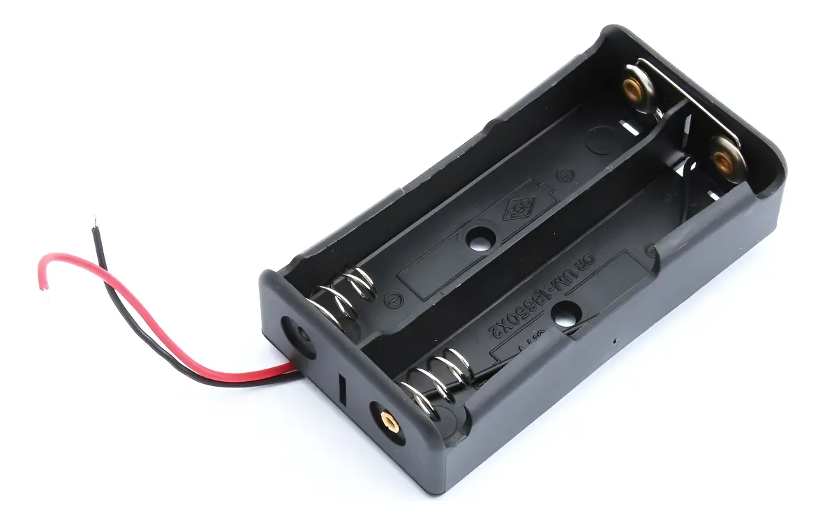
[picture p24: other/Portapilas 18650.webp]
|18650 Battery Holder|A plastic enclosure with metal spring contacts designed to hold one or more 18650 lithium-ion cells securely, providing lead wires or pins to safely connect battery power to a circuit board.|  |[Buy here](https://articulo.mercadolibre.com.mx/MLM-554243991-porta-pilas-baterias-18650-doble-para-dos-baterias-_JM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)|
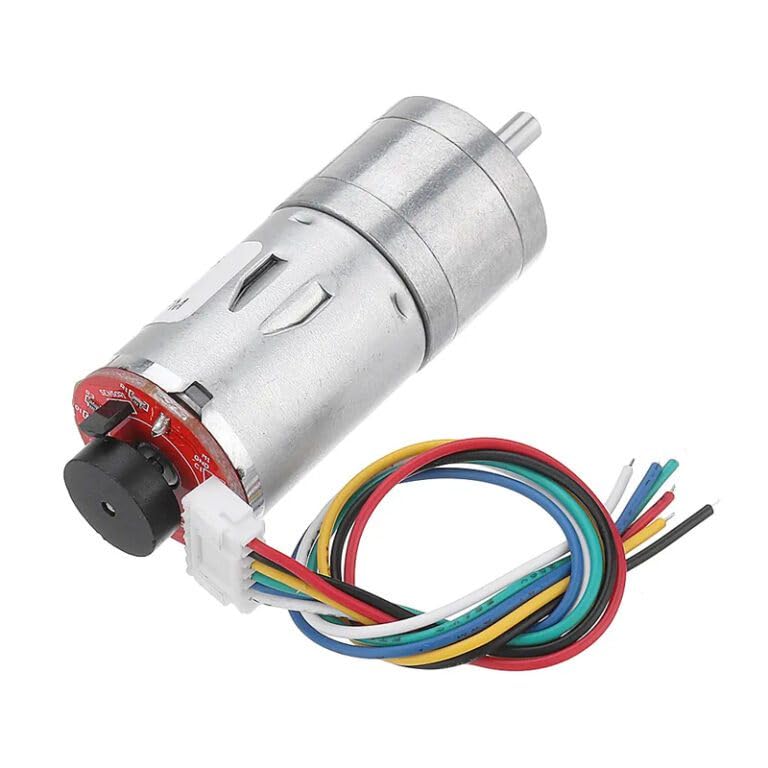
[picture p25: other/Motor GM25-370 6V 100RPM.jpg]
|GM25-370 6V 100 RPM Motor|A compact DC gear motor featuring a 25 mm diameter metal gearbox that produces high torque at low speed (100 RPM at 6V), commonly used in small mobile robots and drive mechanisms requiring precise motion.|  |[Buy here](https://www.amazon.com.mx/Motorreductor-GM-25-370-proyectos-mecatr%C3%B3nica/dp/B0FFPXGHCZ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)|
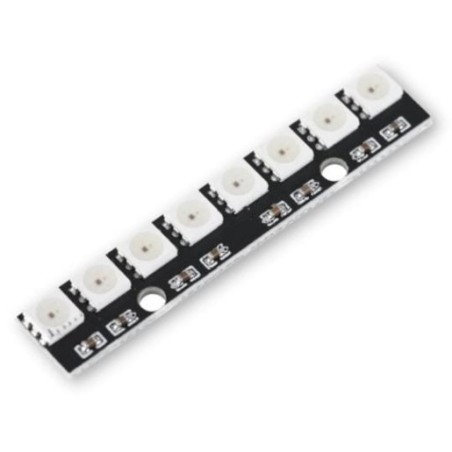
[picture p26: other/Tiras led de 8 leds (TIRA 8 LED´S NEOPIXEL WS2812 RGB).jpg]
|8-LED LED strips (8-LED NEOPIXEL WS2812 RGB Strip)|A flexible or rigid strip featuring eight individually addressable RGB LEDs, allowing full-color customization over a single digital data pin using integrated WS2812 drivers.|  |[Buy here](https://pigra.com.mx/optoelectronica/1260-tira-8-leds-neopixel-ws2812-rgb.html)|
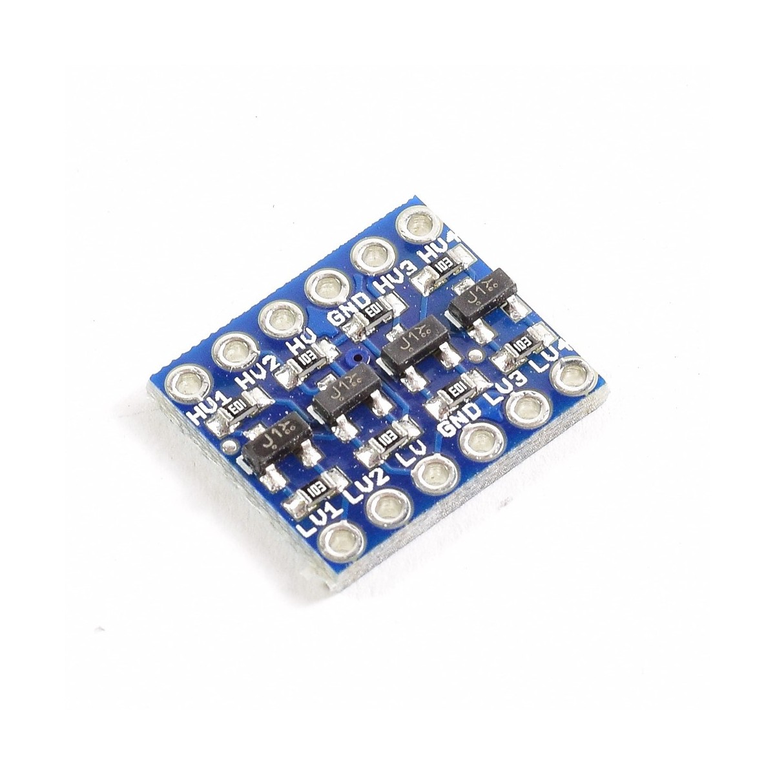
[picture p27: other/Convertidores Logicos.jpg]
|Logic Converters|A bidirectional module designed to safely shift voltage signals between different logic levels (typically 5V and 3.3V) on digital lines like I2C, SPI, or UART, preventing high-voltage microcontrollers from damaging sensitive lower-voltage components.|  |[Buy here](https://naylampmechatronics.com/conversores-ttl/67-conversor-de-nivel-logico-4ch-5v3v.html)|

## Meet the Team

| Photo | Name | Role / Contribution |
|---|---|---|
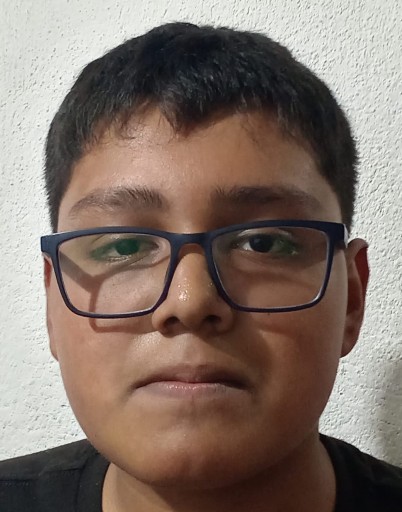
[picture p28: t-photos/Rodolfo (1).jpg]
Rodolfo
|  | Rodolfo Iván Sánchez Andaverde | Programmer |
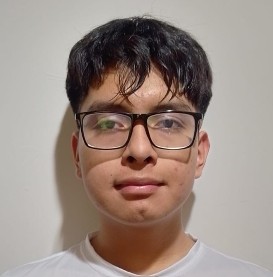
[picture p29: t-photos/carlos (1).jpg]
Carlos Samuel
|  | Carlos Samuel Cortes Esteban | Builder |
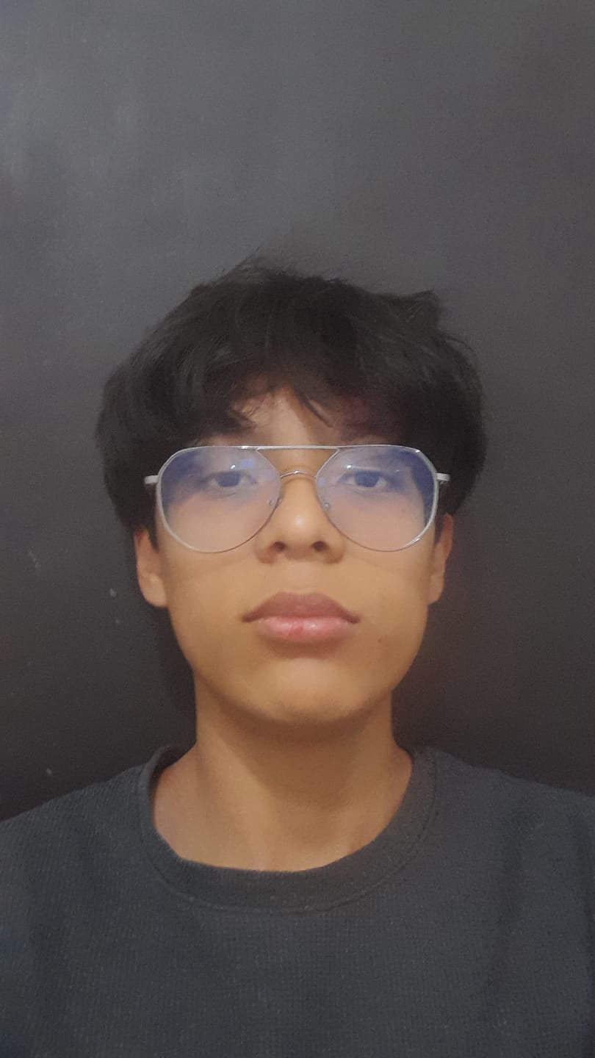
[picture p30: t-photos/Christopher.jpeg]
Christopher
|  | Christopher Pérez Cortés | Programming & Electronics |
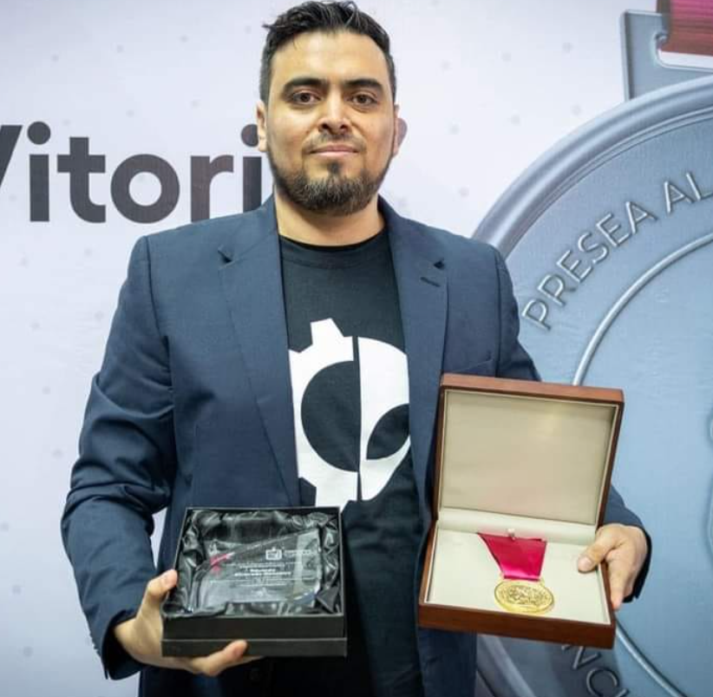
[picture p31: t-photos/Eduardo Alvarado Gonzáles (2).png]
Eduardo
|  | Eduardo Alvarado Gonzalez | Coach and founder |

## Team Photos

<div align="center">
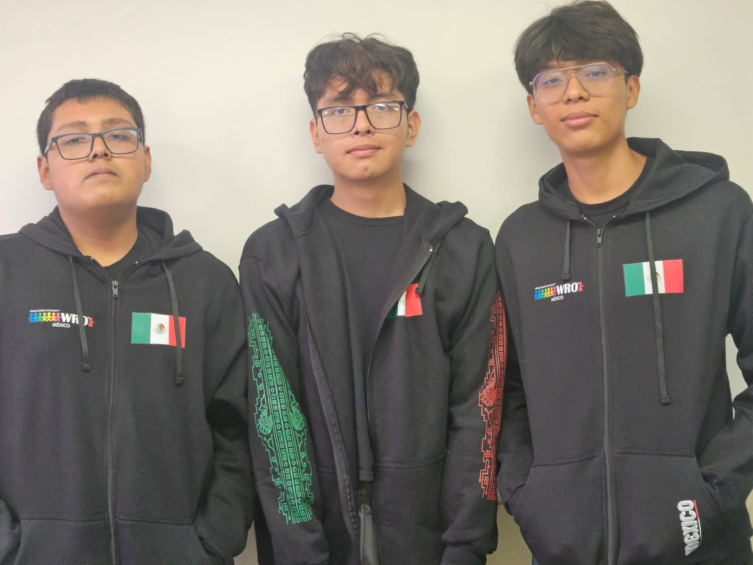
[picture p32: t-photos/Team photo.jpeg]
team-image
</div>

<div align="center">
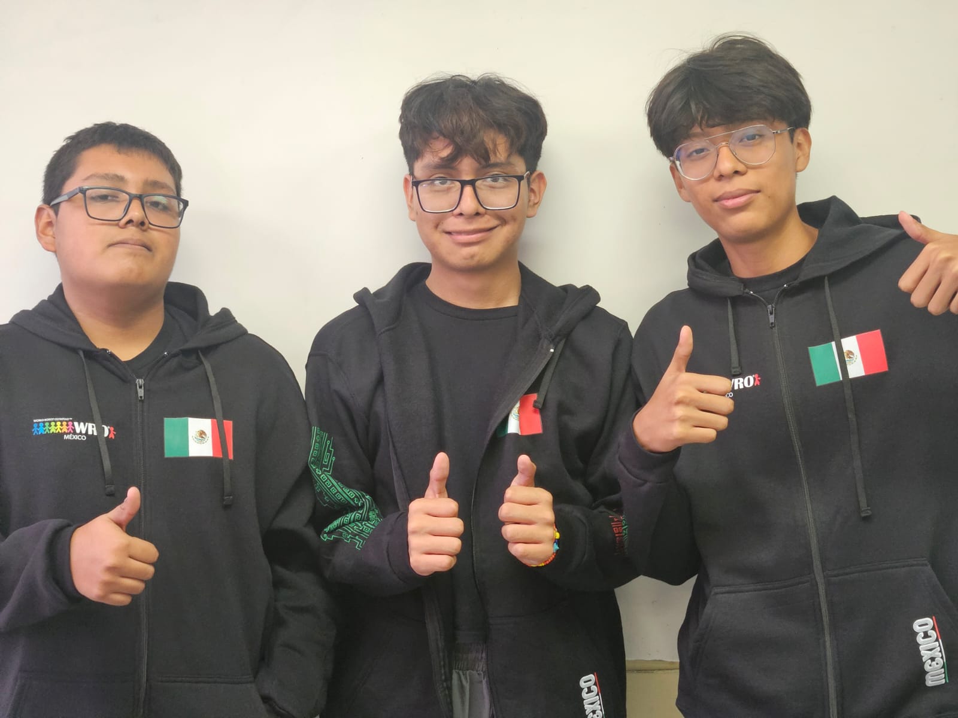
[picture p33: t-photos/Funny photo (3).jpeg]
</div>

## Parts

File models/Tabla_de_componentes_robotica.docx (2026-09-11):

TABLA DE COMPONENTES

Componentes electrónicos del proyecto

No. | Componente | Cantidad | Imagen

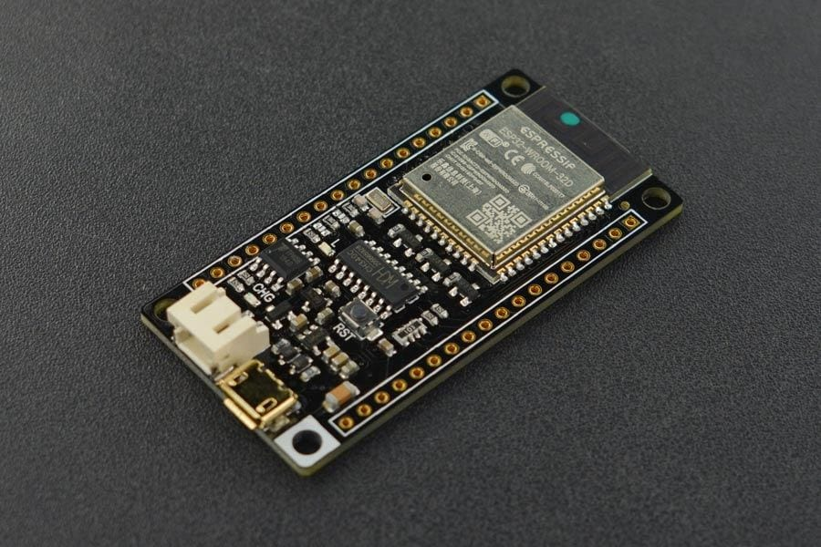
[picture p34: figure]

1 | IoT FireBeetle ESP32 | 2
2 | OpenMV CAM H7 Plus Genuine / OpenMV4 CAM H7 Plus, 5MP | 2

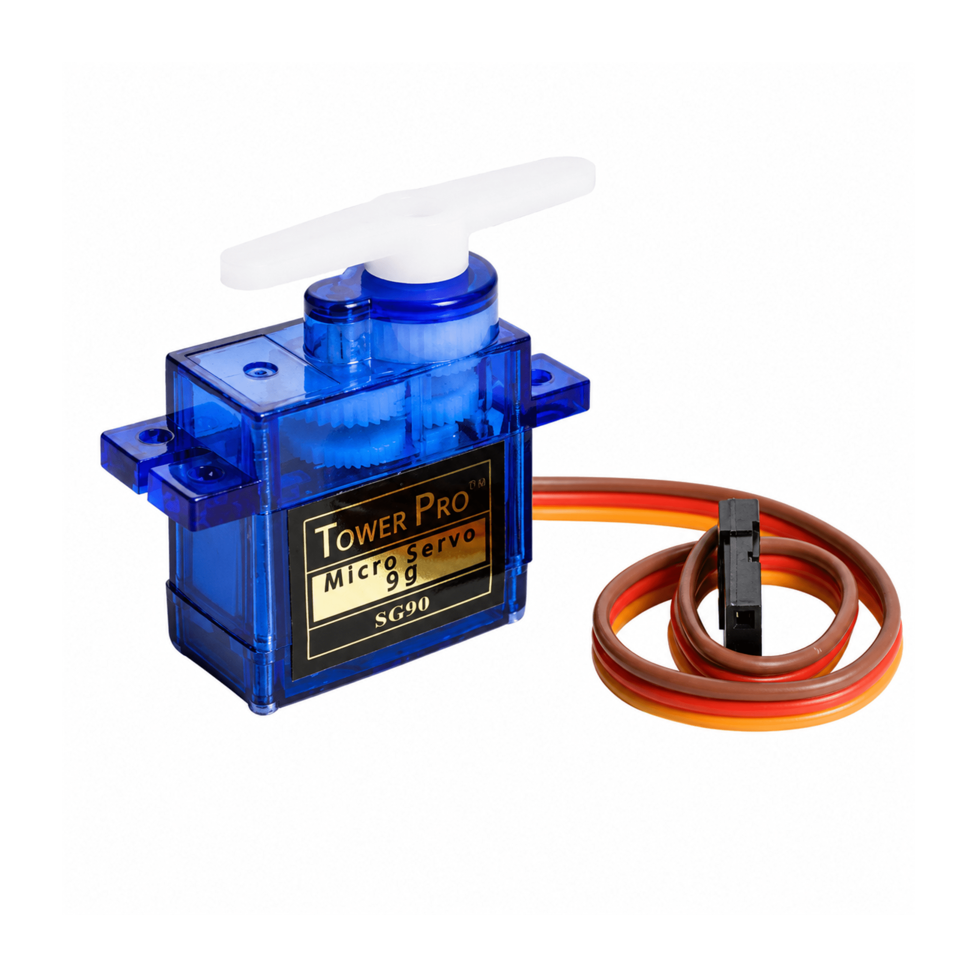
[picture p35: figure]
Servomotor Micro SG90 9G – Tienda Robodacta

3 | Servomotor Micro SG90 9G | 5
4 | Mini interruptor | 2

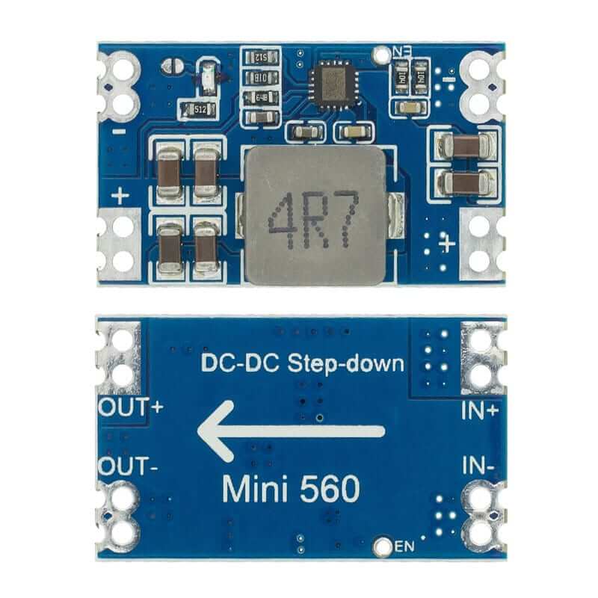
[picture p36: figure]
Mini 560 Regulador Step Down

5 | Regulador Buck Converter Mini (2 de 3.3V y 2 de 5V, | 4

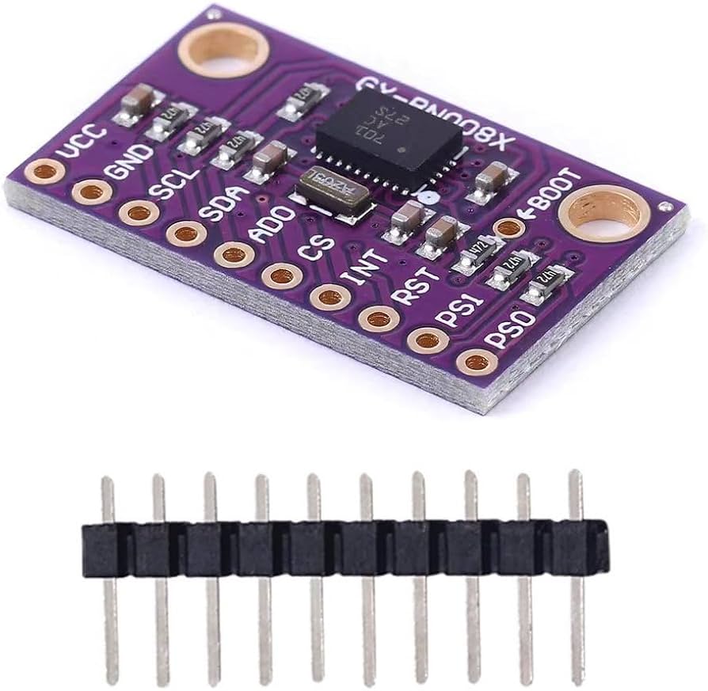
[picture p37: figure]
MerciL BNO080 BNO085 Módulo Sensor de Nueve Ejes, AR VR IMU Acelerómetro Giroscópico Magnetómetro 9DOF AHRS Sensor de Desarrollo para Robótica de Alta Precisión : Amazon.com.mx: Industria, Empresas y Ciencia

6 | BNO080 — módulo sensor de nueve ejes (9DOF AHRS) | 2
7 | Bornera de 2 terminales | 2

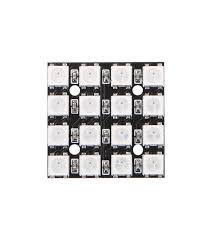
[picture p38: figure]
Unidad LED RGB direccionable NeoPixel Square 4x4 WS2812

8 | Cuadrado LED NeoPixel 4×4 — RGB WS2812 | 1

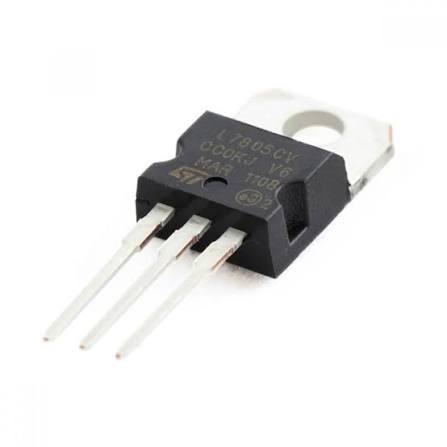
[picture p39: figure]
Regulador L7805CV

9 | reguladores 7805 | 4

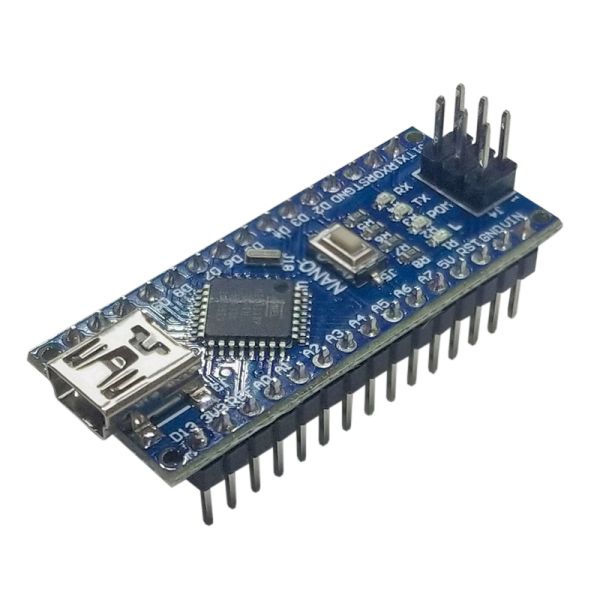
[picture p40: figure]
Arduino Nano V3.0 5v Mini USB (Compatible)

10 | Arduino Nano | 2
11 | TB6612FNG — Driver de motores | 2

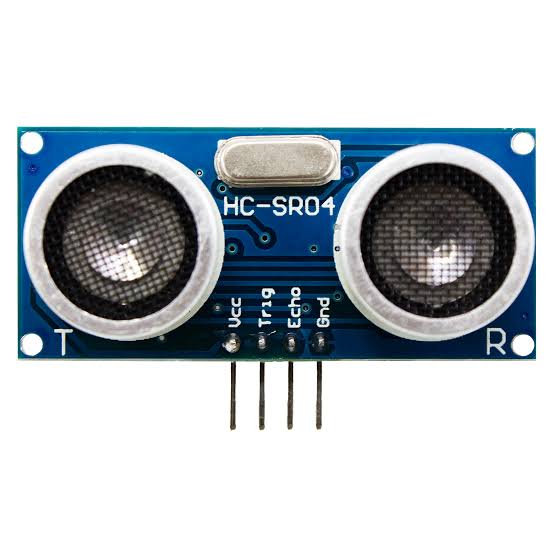
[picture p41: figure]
HC-SR04 sensor ultrasónico de distancia

12 | HC-SR04 — Sensores ultraconicos | 11
13 | Cables Jumper


14 | Pilas 18650 3.7V | 4
15 | Portapilas 18650 | 1

Amazon.com: Pukido MOTOR 6V 100/210/300RPM Motor codificador GM25-370 DC Gear Motor - (Modelo: 210RPM): Juguetes y Juegos

16 | Motor GM25-370 6V 100RPM | 2

Kit soldadura electrónica con cautín de 25 W temp regulable Truper

17 | Kit de cautin | 1


18 | Efaithfix Mini Electric Screwdriver, 66 In 1 Precision Screw | 1


19 | Placa | 2

Cargador USB de pilas Li-Ion cilíndricas Steren Tienda

20 | cargador de pilas 18650 (Cargador USB de pilas Li-Ion cilíndricas de Steren) | 2
21 | Cable micro USB | 2

Multímetro Profesional Steren RMS con detector de voltaje Azul

22 | Multimetro | 1

TIRA 8 LED´S NEOPIXEL WS2812 RGB

23 | Tiras led de 8 leds (TIRA 8 LED´S NEOPIXEL WS2812 RGB) | 1

Convertidor de Nivel Lógico 4 Canales Bidireccional 5V a 3.3V

24 | Convertidores Logicos | 2

Adaptador universal de contactos para viaje con cargador USB/USB C

25 | Adaptador Universal | 2

Pinza con mango rubber grip para electrónica de 5″ corte diagonal Urrea « Urrea Monterrey

26 | Pinza Corte | 2

Pinza para micro corte

27 | Pinza para micro corte | 1

ENR-150 | Alicates de punta larga cónica (con resorte) | ARRIBA | MISUMI

28 | Alicate de punta larga | 1

Pinzas rectas de material acero inoxidable, pinza de punta dentada, laboratorio, 200-300 mm / 8- 200 mm | Walmart en línea

29 | Pinzas Rectas | 1

Cable USB A a Mini-B para Arduino Nano V3.0 - Noticias - Starte Precision Electronic Co., Ltd

30 | Cable USB A a Mini-B para Arduino Nano | 1

HuLuHouse Pinza Pelacables AutomáTica, pela cables, Rojo | 8 Pulgadas 1547 USO Rudo Herramienta de Pelado de Cables para Pelar Cables, Cortar, Crimpar...

31 | Cortador pelacables | 1

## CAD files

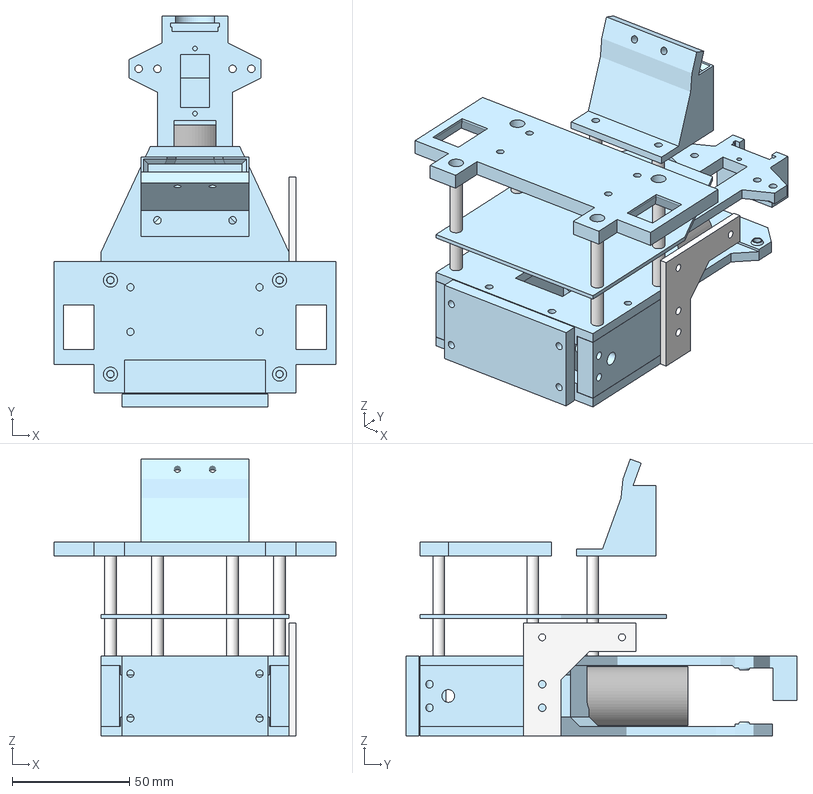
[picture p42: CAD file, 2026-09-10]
models/3D design of the robot—open in Onshape.3mf
120.0 x 166.5 x 117.9 mm
soporte tracero
externo izquierdo
externo derecho
central izquierdo
central derecho
cuerpo inferior
cuerpo superior

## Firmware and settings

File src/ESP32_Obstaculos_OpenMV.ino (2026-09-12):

/*
  ESP32_Obstaculos_OpenMV
  Obstaculos para el robot de India con camara OpenMV.

  Es gemelo de los programas HuskyLens: conserva la misma ley de control,
  los mismos pines del robot y una sola orden de servo y motor por ciclo.
  La unica diferencia importante es la camara: OpenMV envia por UART el ID,
  la posicion y el area del pilar detectado.

  Formato compatible con OPENMV/color_corner.py:
    ID,X,Y,AREA,ROI,COLISION,PARED_NEGRA[,PARKING,X_PARKING,AREA_PARKING]\n
    ID 3 = verde, ID 5 = rojo, ID 0 = sin pilar.
    X llega normalizada de -100 (izquierda) a 100 (derecha).

  Cableado UART2 a 3.3 V:
    OpenMV TX -> FireBeetle D2 / GPIO25 (RX)
    OpenMV RX <- FireBeetle D3 / GPIO26 (TX, opcional)
    OpenMV GND -- FireBeetle GND

  El Nano de ultrasonicos y el BNO085 siguen en I2C IO21/IO22 a 50 kHz.
  La camara usa UART a 19200 baudios y no comparte el bus I2C.
*/

#include <Arduino.h>
#include <Wire.h>
#include <Adafruit_BNO08x.h>
#include <Preferences.h>
#include <ctype.h>
#include <string.h>
#include <math.h>

// ====================================================================
//                  VARIABLES PARA CALIBRAR EL ROBOT
// ====================================================================

// Los Kp del pasillo y de la camara se ajustan aqui. Despues hay que volver
// a cargar el programa al ESP32. Ningun valor guardado en la memoria puede
// reemplazarlos. Los demas parametros conservan sus ajustes opcionales por
// monitor serie.

// ------------------------- Velocidad --------------------------------

// Arath rueda al 40 %. La V2 de India rueda al 70 %, pero esa velocidad
// esta calibrada contra sus maniobras de rescate, que aqui no existen.
// Confirma la trayectoria a 40 y sube de cinco en cinco.
constexpr uint8_t VELOCIDAD_DEFECTO = 70;

// El sentido fisico del motor de este robot sale invertido.
constexpr bool INVERTIR_DIRECCION_MOTOR = true;

// ---------------------- Direccion por pasillo -----------------------

// diferencia = (S1 + S2) - (S4 + S5), en centimetros.
// S1 y S2 miran a la izquierda, S4 y S5 a la derecha.
//
// Control P del pasillo:
//   error = izquierda - derecha
//   correccion = Kp * error
// Arath: angulo = 90 - 0.18 * error, con tope de 18 grados.
constexpr float KP_PASILLO = 4.0f;  // <--- AJUSTAR KP DE PASILLO AQUI
constexpr float TOPE_PASILLO_DEFECTO = 30.0f;

// Cambiar a 1 si el robot se pega a la pared en vez de separarse.
constexpr int8_t DIRECCION_SERVO_PASILLO = -1;

// Recorte de los laterales antes de restar. Ver la nota del encabezado.
constexpr float MAXIMA_DISTANCIA_LATERAL_CM = 150.0f;

// ----------------------- Direccion por camara -----------------------

// OpenMV envia X normalizada entre -100 y 100. El objetivo 62.5 y Kp 0.20
// producen el mismo angulo que objetivo 200 y Kp 0.0625 en HuskyLens 2.
// Rojo a la izquierda de la imagen -> el robot pasa por la derecha.
constexpr float OBJETIVO_X_DEFECTO = 35.0f;
constexpr float KP_CAMARA = 1.0f;  // <--- AJUSTAR KP DE CAMARA AQUI
constexpr float TOPE_CAMARA_DEFECTO = 30.0f;

// Cambiar a -1 si el robot rebasa por el lado equivocado.
constexpr int8_t DIRECCION_SERVO_CAMARA = 1;

// IDs enviados por OPENMV/color_corner.py.
constexpr uint8_t ID_ROJO = 5;
constexpr uint8_t ID_VERDE = 3;

// El firmware OpenMV ya filtra blobs pequenos. Este segundo filtro evita
// usar como objetivo una deteccion con area casi nula.
constexpr uint16_t AREA_MINIMA_PILAR_PX = 30;

// --------------------------- Mision ---------------------------------

constexpr uint8_t ESQUINAS_PARA_TERMINAR = 12;  // 3 vueltas
constexpr float GRADOS_POR_ESQUINA = 90.0f;

// Arath cruza la linea de meta y sigue 250 ms antes de frenar.
constexpr unsigned long MILISEGUNDOS_TRAMO_FINAL = 250;

// ------------------------ Ritmo del ciclo ---------------------------

// 40 Hz. OpenMV se recibe sin bloquear por UART y el paquete del Nano tarda
// unos 2 ms, asi que el ciclo cierra con margen de sobra.
constexpr unsigned long PERIODO_CICLO_MS = 25;

// ====================================================================
//                             PINES
// ====================================================================

constexpr uint8_t PIN_SERVO = 27;  // D4 / IO27
constexpr uint8_t PIN_MOTOR_PWM = D6;
constexpr uint8_t PIN_MOTOR_AIN2 = D7;
constexpr uint8_t PIN_MOTOR_AIN1 = D8;
constexpr uint8_t PIN_ENCODER_A = D5;

constexpr int8_t PIN_OPENMV_RX = 25;  // D2, recibe desde TX de OpenMV
constexpr int8_t PIN_OPENMV_TX = 26;  // D3, envia hacia RX de OpenMV

constexpr uint8_t PIN_SDA = 21;
constexpr uint8_t PIN_SCL = 22;

constexpr uint8_t DIRECCION_NANO = 0x08;
constexpr uint8_t DIRECCION_BNO085_PRIMARIA = 0x4B;
constexpr uint8_t DIRECCION_BNO085_SECUNDARIA = 0x4A;

// El bus va a 50 kHz por el Nano de 5 V: sus pull-ups son de 3.3 V y el
// margen de HIGH es de apenas 0.3 V. Ver extras/README_I2C_SENSORES.md.
constexpr uint32_t FRECUENCIA_I2C_HZ = 50000;
constexpr uint16_t TIMEOUT_I2C_MS = 10;

constexpr uint32_t OPENMV_BAUD = 19200;
constexpr unsigned long OPENMV_TIMEOUT_MS = 500;
constexpr int OPENMV_X_MIN = -100;
constexpr int OPENMV_X_MAX = 100;
constexpr int OPENMV_X_TOLERANCIA = 5;
constexpr int OPENMV_ALTO_IMAGEN_PX = 240;
constexpr int OPENMV_CAMPOS_MINIMOS = 6;
constexpr int OPENMV_CAMPOS_MAXIMOS = 10;
constexpr size_t OPENMV_LINEA_BYTES = 128;
constexpr size_t OPENMV_BUFFER_RX_BYTES = 512;
constexpr int OPENMV_MAXIMO_ATRASO_BYTES = 128;
constexpr uint8_t OPENMV_LINEAS_POR_CICLO = 8;
constexpr unsigned long OPENMV_AVISO_INVALIDO_MS = 1000;

// ====================================================================
//                      CONSTANTES DE HARDWARE
// ====================================================================

constexpr uint8_t CANTIDAD_SENSORES = 5;
constexpr uint8_t BYTES_PAQUETE = CANTIDAD_SENSORES * 2;
constexpr uint16_t DISTANCIA_INVALIDA_MM = 0xFFFF;
constexpr uint16_t DISTANCIA_SIN_ECO_MM = 2000;
constexpr unsigned long TIMEOUT_SENSORES_MS = 250;

constexpr uint8_t INDICE_IZQ_90 = 0;   // S1
constexpr uint8_t INDICE_IZQ_25 = 1;   // S2
constexpr uint8_t INDICE_FRONTAL = 2;  // S3
constexpr uint8_t INDICE_DER_25 = 3;   // S4
constexpr uint8_t INDICE_DER_90 = 4;   // S5

constexpr int SERVO_CENTRO_GRADOS = 90;
constexpr int SERVO_CORRECCION_MAXIMA_GRADOS = 40;
constexpr uint16_t SERVO_PULSO_MINIMO_US = 500;
constexpr uint16_t SERVO_PULSO_MAXIMO_US = 2500;
constexpr uint32_t SERVO_PWM_HZ = 50;
constexpr uint8_t SERVO_PWM_BITS = 16;
constexpr uint32_t MOTOR_PWM_HZ = 20000;
constexpr uint8_t MOTOR_PWM_BITS = 10;

#if ESP_ARDUINO_VERSION_MAJOR < 3
constexpr uint8_t CANAL_PWM_SERVO = 0;
constexpr uint8_t CANAL_PWM_MOTOR = 1;
#endif

// El interruptor del juez corta la potencia del motor, no la del ESP32. El
// PWM se prepara desde el encendido y la ronda arranca cuando el encoder
// confirma que el robot de verdad se movio.
constexpr uint32_t PULSOS_PARA_ARRANCAR = 4;

constexpr uint32_t BNO085_INTERVALO_REPORTE_US = 10000;
constexpr unsigned long BNO085_REINTENTO_MS = 1000;
constexpr unsigned long BNO085_SIN_DATOS_MS = 2000;
constexpr float MAXIMO_SALTO_RUMBO_GRADOS = 90.0f;

constexpr uint8_t BRILLO_LEDS_PORCENTAJE = 20;
constexpr unsigned long INTERVALO_BRILLO_MS = 2000;
constexpr unsigned long INTERVALO_TELEMETRIA_MS = 500;

constexpr uint8_t SERIAL_LINEA_BYTES = 48;

// Tope de bytes atendidos por ciclo: pegar un texto largo no debe retrasar
// los sensores ni el servo.
constexpr uint8_t SERIAL_BYTES_POR_CICLO = 32;

// Espacio propio para que los ajustes de OpenMV no se mezclen con los de
// HuskyLens 1 o 2.
constexpr char NVS_ESPACIO[] = "openmv";

// ====================================================================
//                       COMPROBACIONES EN FRIO
// ====================================================================

static_assert(VELOCIDAD_DEFECTO > 0 && VELOCIDAD_DEFECTO <= 100,
              "La velocidad va de 1 a 100");
static_assert(DIRECCION_SERVO_PASILLO == 1 || DIRECCION_SERVO_PASILLO == -1,
              "La direccion del pasillo solo puede ser 1 o -1");
static_assert(DIRECCION_SERVO_CAMARA == 1 || DIRECCION_SERVO_CAMARA == -1,
              "La direccion de la camara solo puede ser 1 o -1");
static_assert(TOPE_PASILLO_DEFECTO <= SERVO_CORRECCION_MAXIMA_GRADOS,
              "El tope del pasillo no cabe en el recorrido del servo");
static_assert(TOPE_CAMARA_DEFECTO <= SERVO_CORRECCION_MAXIMA_GRADOS,
              "El tope de la camara no cabe en el recorrido del servo");
static_assert(ID_ROJO != ID_VERDE, "Los IDs de color deben ser distintos");
static_assert(KP_PASILLO >= 0.0f, "Kp de pasillo no puede ser negativo");
static_assert(KP_CAMARA >= 0.0f, "Kp de camara no puede ser negativo");
static_assert(ESQUINAS_PARA_TERMINAR > 0, "Hacen falta esquinas que contar");
static_assert(PERIODO_CICLO_MS > 0, "El periodo del ciclo no puede ser 0");

// ====================================================================
//                             ESTADO
// ====================================================================

enum class Color : uint8_t { NINGUNO, ROJO, VERDE };

enum class Fase : uint8_t { ESPERANDO, RODANDO, TRAMO_FINAL, TERMINADO };

struct Pilar {
  Color color = Color::NINGUNO;
  float xCamara = 0.0f;  // normalizada: -100 izquierda, +100 derecha
  uint16_t areaPx = 0;
  int16_t yPx = -1;
  uint8_t roi = 0;
  uint8_t id = 0;
};

// Lo que se calibra en la mesa. Arranca en las constantes de arriba, se
// cambia por el monitor serie y, si se guarda, sobrevive al apagon. Va
// declarado aqui, antes de cualquier funcion, porque el IDE de Arduino
// genera los prototipos al principio del archivo.
struct Ajustes {
  float topePasillo = TOPE_PASILLO_DEFECTO;
  float topeCamara = TOPE_CAMARA_DEFECTO;
  float objetivoX = OBJETIVO_X_DEFECTO;
  uint8_t velocidad = VELOCIDAD_DEFECTO;
};

Adafruit_BNO08x bno085;
sh2_SensorValue_t valorBno085;
HardwareSerial openMVSerial(2);

Fase fase = Fase::ESPERANDO;
Pilar pilar;
Ajustes ajustes;
Preferences memoria;
bool telemetriaActiva = true;

uint16_t distanciasMm[CANTIDAD_SENSORES] = {
    DISTANCIA_SIN_ECO_MM, DISTANCIA_SIN_ECO_MM, DISTANCIA_SIN_ECO_MM,
    DISTANCIA_SIN_ECO_MM, DISTANCIA_SIN_ECO_MM};
unsigned long ultimoPaqueteMs = 0;
bool hayDistancias = false;

bool servoListo = false;
bool motorListo = false;
int ultimoAnguloEscrito = -1;
uint8_t ultimaVelocidadEscrita = 255;

volatile uint32_t pulsosEncoder = 0;

bool bno085Listo = false;
bool bno085ConRumbo = false;
float rumboAnteriorGrados = 0.0f;
float giroAcumuladoGrados = 0.0f;
uint8_t esquinas = 0;
unsigned long ultimoReintentoBnoMs = 0;
unsigned long ultimoCuadroBnoMs = 0;

bool camaraLista = false;
unsigned long ultimoPaqueteCamaraMs = 0;
unsigned long ultimoAvisoOpenMvMs = 0;
uint32_t tramasOpenMvValidas = 0;
uint32_t tramasOpenMvInvalidas = 0;
char lineaOpenMV[OPENMV_LINEA_BYTES];
size_t largoLineaOpenMV = 0;
bool descartandoLineaOpenMV = false;

unsigned long inicioRondaMs = 0;
unsigned long finTramoFinalMs = 0;
unsigned long ultimoCicloMs = 0;
unsigned long ultimoBrilloMs = 0;
unsigned long ultimaTelemetriaMs = 0;

char lineaSerial[SERIAL_LINEA_BYTES];
uint8_t largoLineaSerial = 0;

// ====================================================================
//                            UTILIDADES
// ====================================================================

float normalizarDelta(float gradosDelta) {
  while (gradosDelta > 180.0f) gradosDelta -= 360.0f;
  while (gradosDelta < -180.0f) gradosDelta += 360.0f;
  return gradosDelta;
}

float distanciaLateralCm(uint16_t distanciaMm) {
  const float cm = static_cast<float>(distanciaMm) / 10.0f;
  return cm > MAXIMA_DISTANCIA_LATERAL_CM ? MAXIMA_DISTANCIA_LATERAL_CM : cm;
}

// ====================================================================
//                          SERVO Y MOTOR
// ====================================================================

bool iniciarServo() {
#if ESP_ARDUINO_VERSION_MAJOR >= 3
  return ledcAttach(PIN_SERVO, SERVO_PWM_HZ, SERVO_PWM_BITS);
#else
  ledcSetup(CANAL_PWM_SERVO, SERVO_PWM_HZ, SERVO_PWM_BITS);
  ledcAttachPin(PIN_SERVO, CANAL_PWM_SERVO);
  return true;
#endif
}

void escribirServo(int grados) {
  if (!servoListo) {
    return;
  }

  grados = constrain(grados, 0, 180);

  const uint32_t pulsoUs =
      SERVO_PULSO_MINIMO_US +
      (static_cast<uint32_t>(grados) *
       (SERVO_PULSO_MAXIMO_US - SERVO_PULSO_MINIMO_US)) /
          180UL;

  constexpr uint32_t PERIODO_US = 1000000UL / SERVO_PWM_HZ;
  constexpr uint32_t DUTY_MAXIMO = (1UL << SERVO_PWM_BITS) - 1UL;

  const uint32_t duty =
      (pulsoUs * DUTY_MAXIMO + PERIODO_US / 2UL) / PERIODO_US;

#if ESP_ARDUINO_VERSION_MAJOR >= 3
  ledcWrite(PIN_SERVO, duty);
#else
  ledcWrite(CANAL_PWM_SERVO, duty);
#endif
}

// Unico punto del programa que mueve el servo.
void aplicarDireccion(float grados) {
  grados = constrain(
      grados,
      static_cast<float>(SERVO_CENTRO_GRADOS -
                         SERVO_CORRECCION_MAXIMA_GRADOS),
      static_cast<float>(SERVO_CENTRO_GRADOS +
                         SERVO_CORRECCION_MAXIMA_GRADOS));

  const int redondeado = static_cast<int>(lroundf(grados));
  if (redondeado != ultimoAnguloEscrito) {
    escribirServo(redondeado);
    ultimoAnguloEscrito = redondeado;
  }
}

bool iniciarMotor() {
  pinMode(PIN_MOTOR_AIN1, OUTPUT);
  pinMode(PIN_MOTOR_AIN2, OUTPUT);
  digitalWrite(PIN_MOTOR_AIN1, LOW);
  digitalWrite(PIN_MOTOR_AIN2, LOW);

#if ESP_ARDUINO_VERSION_MAJOR >= 3
  return ledcAttach(PIN_MOTOR_PWM, MOTOR_PWM_HZ, MOTOR_PWM_BITS);
#else
  ledcSetup(CANAL_PWM_MOTOR, MOTOR_PWM_HZ, MOTOR_PWM_BITS);
  ledcAttachPin(PIN_MOTOR_PWM, CANAL_PWM_MOTOR);
  return true;
#endif
}

// Unico punto del programa que mueve el motor. Siempre hacia adelante:
// este programa no tiene reversas ni maniobras de rescate.
void aplicarMotor(uint8_t porcentaje) {
  if (!motorListo) {
    return;
  }

  porcentaje = constrain(porcentaje, 0, 100);

  if (porcentaje == 0) {
    digitalWrite(PIN_MOTOR_AIN1, LOW);
    digitalWrite(PIN_MOTOR_AIN2, LOW);
  } else {
    digitalWrite(PIN_MOTOR_AIN1, INVERTIR_DIRECCION_MOTOR ? LOW : HIGH);
    digitalWrite(PIN_MOTOR_AIN2, INVERTIR_DIRECCION_MOTOR ? HIGH : LOW);
  }

  if (porcentaje == ultimaVelocidadEscrita) {
    return;
  }

  constexpr uint32_t DUTY_MAXIMO = (1UL << MOTOR_PWM_BITS) - 1UL;
  const uint32_t duty =
      (static_cast<uint32_t>(porcentaje) * DUTY_MAXIMO + 50UL) / 100UL;

#if ESP_ARDUINO_VERSION_MAJOR >= 3
  ledcWrite(PIN_MOTOR_PWM, duty);
#else
  ledcWrite(CANAL_PWM_MOTOR, duty);
#endif
  ultimaVelocidadEscrita = porcentaje;
}

void IRAM_ATTR pulsoEncoder() { pulsosEncoder = pulsosEncoder + 1; }

void iniciarEncoder() {
  pinMode(PIN_ENCODER_A, INPUT_PULLUP);
  attachInterrupt(digitalPinToInterrupt(PIN_ENCODER_A), pulsoEncoder, RISING);
}

uint32_t leerPulsosEncoder() {
  noInterrupts();
  const uint32_t pulsos = pulsosEncoder;
  interrupts();
  return pulsos;
}

// ====================================================================
//                       ULTRASONICOS POR I2C
// ====================================================================

bool leerDistancias() {
  const uint8_t recibidos =
      Wire.requestFrom(static_cast<uint8_t>(DIRECCION_NANO),
                       static_cast<uint8_t>(BYTES_PAQUETE));

  if (recibidos != BYTES_PAQUETE) {
    while (Wire.available()) {
      Wire.read();
    }
    return false;
  }

  for (uint8_t i = 0; i < CANTIDAD_SENSORES; ++i) {
    const uint8_t bajo = Wire.read();
    const uint8_t alto = Wire.read();
    const uint16_t valor =
        static_cast<uint16_t>(bajo) | (static_cast<uint16_t>(alto) << 8);
    distanciasMm[i] =
        valor == DISTANCIA_INVALIDA_MM ? DISTANCIA_SIN_ECO_MM : valor;
  }

  return true;
}

void enviarBrilloLeds(uint8_t porcentaje) {
  Wire.beginTransmission(DIRECCION_NANO);
  Wire.write(static_cast<uint8_t>(constrain(porcentaje, 0, 100)));
  Wire.endTransmission();
}

// ====================================================================
//                         OPENMV POR UART
// ====================================================================

Color colorDeId(long id) {
  if (id == ID_ROJO) return Color::ROJO;
  if (id == ID_VERDE) return Color::VERDE;
  return Color::NINGUNO;
}

long limitarLong(long valor, long minimo, long maximo) {
  if (valor < minimo) return minimo;
  if (valor > maximo) return maximo;
  return valor;
}

// Separa una linea CSV numerica. Los campos posteriores al decimo se ignoran
// para no romper el enlace si el firmware agrega telemetria en el futuro.
int separarCamposOpenMV(const char *linea, long *campos, int capacidad) {
  int cantidad = 0;
  const char *cursor = linea;

  while (*cursor != '\0') {
    while (*cursor == ' ' || *cursor == '\t') ++cursor;
    if (*cursor == '\0') break;

    bool negativo = false;
    if (*cursor == '+' || *cursor == '-') {
      negativo = *cursor == '-';
      ++cursor;
    }
    if (*cursor < '0' || *cursor > '9') return -1;

    long valor = 0;
    uint8_t digitos = 0;
    while (*cursor >= '0' && *cursor <= '9') {
      if (digitos >= 9) return -1;
      valor = valor * 10L + static_cast<long>(*cursor - '0');
      ++digitos;
      ++cursor;
    }
    if (negativo) valor = -valor;
    if (cantidad < capacidad) campos[cantidad] = valor;
    ++cantidad;

    while (*cursor == ' ' || *cursor == '\t') ++cursor;
    if (*cursor == ',') {
      ++cursor;
    } else if (*cursor != '\0') {
      return -1;
    }
  }

  return cantidad;
}

bool procesarLineaOpenMV(const char *linea, unsigned long ahoraMs) {
  long campos[OPENMV_CAMPOS_MAXIMOS] = {0};
  const int recibidos =
      separarCamposOpenMV(linea, campos, OPENMV_CAMPOS_MAXIMOS);

  if (recibidos < OPENMV_CAMPOS_MINIMOS) return false;

  const long id = campos[0];
  const long x = campos[1];
  const long y = campos[2];
  const long area = campos[3];
  const long roi = campos[4];
  const long colision = campos[5];

  if ((id != 0 && id != ID_ROJO && id != ID_VERDE) ||
      roi < 0 || roi > 2 ||
      (colision != 0 && colision != ID_ROJO && colision != ID_VERDE)) {
    return false;
  }

  Pilar nuevo;
  if (id != 0) {
    if (x < OPENMV_X_MIN - OPENMV_X_TOLERANCIA ||
        x > OPENMV_X_MAX + OPENMV_X_TOLERANCIA ||
        y < 0 || y >= OPENMV_ALTO_IMAGEN_PX ||
        area < AREA_MINIMA_PILAR_PX || area > UINT16_MAX ||
        (roi != 1 && roi != 2)) {
      return false;
    }

    nuevo.color = colorDeId(id);
    nuevo.id = static_cast<uint8_t>(id);
    nuevo.xCamara = static_cast<float>(
        limitarLong(x, OPENMV_X_MIN, OPENMV_X_MAX));
    nuevo.yPx = static_cast<int16_t>(y);
    nuevo.areaPx = static_cast<uint16_t>(area);
    nuevo.roi = static_cast<uint8_t>(roi);
  }

  pilar = nuevo;
  ultimoPaqueteCamaraMs = ahoraMs;
  ++tramasOpenMvValidas;

  if (!camaraLista) {
    camaraLista = true;
    Serial.println("OpenMV: enlace UART establecido");
  }
  return true;
}

void avisarTramaOpenMvInvalida(unsigned long ahoraMs) {
  ++tramasOpenMvInvalidas;
  if (ahoraMs - ultimoAvisoOpenMvMs >= OPENMV_AVISO_INVALIDO_MS) {
    ultimoAvisoOpenMvMs = ahoraMs;
    Serial.println("AVISO: trama OpenMV invalida");
  }
}

void iniciarCamara() {
  openMVSerial.setRxBufferSize(OPENMV_BUFFER_RX_BYTES);
  openMVSerial.begin(OPENMV_BAUD, SERIAL_8N1,
                     PIN_OPENMV_RX, PIN_OPENMV_TX);
  Serial.print("OpenMV UART2 lista: RX GPIO");
  Serial.print(PIN_OPENMV_RX);
  Serial.print(", TX GPIO");
  Serial.print(PIN_OPENMV_TX);
  Serial.print(", ");
  Serial.print(OPENMV_BAUD);
  Serial.println(" baudios");
}
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
void loop() {
  const unsigned long ahoraMs = millis();

  if (ahoraMs - ultimoCicloMs < PERIODO_CICLO_MS) {
    return;
  }
  ultimoCicloMs = ahoraMs;

  // ---------------- 1. percepcion ----------------

  actualizarCamara(ahoraMs);

  if (leerDistancias()) {
    ultimoPaqueteMs = ahoraMs;
    hayDistancias = true;
  } else if (hayDistancias &&
             ahoraMs - ultimoPaqueteMs > TIMEOUT_SENSORES_MS) {
    hayDistancias = false;
    Serial.println("AVISO: sin paquete del Nano");
  }

  actualizarBno(ahoraMs);

  // ---------------- 2. arranque de la ronda ----------------

  if (fase == Fase::ESPERANDO &&
      leerPulsosEncoder() >= PULSOS_PARA_ARRANCAR) {
    fase = Fase::RODANDO;
    inicioRondaMs = ahoraMs;
    giroAcumuladoGrados = 0.0f;
    esquinas = 0;
    Serial.println("Ronda iniciada");
  }

  if (fase == Fase::TRAMO_FINAL && ahoraMs >= finTramoFinalMs) {
    fase = Fase::TERMINADO;
    Serial.print("*** MISION TERMINADA en ");
    Serial.print((ahoraMs - inicioRondaMs) / 1000.0f, 1);
    Serial.println(" s ***");
  }

  // ---------------- 3. un angulo y una velocidad ----------------

  float angulo = SERVO_CENTRO_GRADOS;
  uint8_t velocidad = 0;

  if (fase == Fase::TERMINADO) {
    angulo = SERVO_CENTRO_GRADOS;
    velocidad = 0;
  } else if (!hayDistancias) {
    // Sin sensores el robot no sabe donde esta el pasillo. Frenar es la
    // unica respuesta honesta.
    angulo = SERVO_CENTRO_GRADOS;
    velocidad = 0;
  } else if (fase == Fase::TRAMO_FINAL) {
    // Cruzando la meta manda el pasillo: no hay que rebasar nada mas.
    angulo = anguloPorPasillo();
    velocidad = ajustes.velocidad;
  } else if (pilar.color != Color::NINGUNO) {
    angulo = anguloPorCamara();
    velocidad = ajustes.velocidad;
  } else {
    angulo = anguloPorPasillo();
    velocidad = ajustes.velocidad;
  }

  // ---------------- 4. las dos unicas escrituras ----------------

  aplicarDireccion(angulo);
  aplicarMotor(velocidad);

  // ---------------- 5. mantenimiento ----------------

  atenderSerial();

  if (ahoraMs - ultimoBrilloMs >= INTERVALO_BRILLO_MS) {
    ultimoBrilloMs = ahoraMs;
    enviarBrilloLeds(BRILLO_LEDS_PORCENTAJE);
  }

  if (telemetriaActiva &&
      ahoraMs - ultimaTelemetriaMs >= INTERVALO_TELEMETRIA_MS) {
    ultimaTelemetriaMs = ahoraMs;
    imprimirTelemetria(angulo, velocidad);
  }
}

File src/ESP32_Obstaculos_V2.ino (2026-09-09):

/*
  Version 2: obstaculos, seguimiento de pasillo y telemetria de ronda.

  Prioridad de direccion:

    1. Si S3 detecta una pared demasiado cerca, el robot frena, centra
       el servo y retrocede hasta recuperar espacio.
    2. Mientras OpenMV vea un pilar valido, la camara controla el servo.
    3. Al perder el pilar, el servo vuelve gradualmente al objetivo que
       calcula el PID del pasillo.
    4. Sin pilar, los ultrasonicos laterales controlan normalmente el servo.

  El BNO085 no dirige: solo cuenta las vueltas de la mision.
*/

#include <Arduino.h>
#include <Wire.h>
#include <Adafruit_BNO08x.h>
#include <WiFi.h>
#include <WebServer.h>
#include <esp_arduino_version.h>
#include <math.h>

// ====================================================================
//                  VARIABLES PARA CALIBRAR EL ROBOT
// ====================================================================

// ----------------------- Velocidad del motor ------------------------

constexpr uint8_t MOTOR_SPEED_PERCENT = 70; /////////////////////////////////speed
constexpr uint8_t MOTOR_CORNER_SPEED_PERCENT = 50; /////////////////////////////////speed

// Al detectar un pilar, limita inmediatamente la velocidad a este valor.
// Conforme el pilar se acerca, baja hasta MOTOR_CORNER_SPEED_PERCENT.
constexpr uint8_t MOTOR_PILLAR_FAR_SPEED_PERCENT = 70; ////////////////////////////////speed
constexpr bool INVERT_MOTOR_DIRECTION = true;

// Maniobra al detectar un color dentro de COLLISION_ROI.
constexpr uint8_t COLLISION_REVERSE_SPEED_PERCENT = 30;
constexpr unsigned long COLLISION_STOP_BEFORE_REVERSE_MS = 100;
constexpr uint16_t COLLISION_REVERSE_DISTANCE_MM = 100;
constexpr unsigned long COLLISION_REVERSE_MAX_MS = 1500;
constexpr uint8_t COLLISION_TRIGGER_CONFIRM_FRAMES = 2;
constexpr uint8_t COLLISION_CLEAR_CONFIRM_FRAMES = 3;

constexpr uint8_t MOTOR_PWM_PIN = D6;
constexpr uint8_t MOTOR_AIN2_PIN = D7;
constexpr uint8_t MOTOR_AIN1_PIN = D8;

// El interruptor del juez corta la potencia del motor, pero el ESP32 sigue
// preparando este PWM. La rampa comienza cuando el encoder confirma movimiento.
constexpr uint8_t MOTOR_START_DETECTION_PERCENT = 45;
constexpr uint8_t ENCODER_START_PULSES = 4;
constexpr unsigned long ENCODER_DETECTION_WINDOW_MS = 600;
constexpr unsigned long MOTOR_SOFT_START_DURATION_MS = 5000;
constexpr uint8_t ENCODER_A_PIN = D5;
constexpr uint8_t ENCODER_B_PIN = D9;

// Calibracion de 1 metro: prueba 1 = 3870, prueba 2 = 3988.
// Promedio = 3929 pulsos/m = 0.2545 mm por pulso.
constexpr float ENCODER_MM_PER_PULSE = 1000.0f / 3929.0f;
constexpr int8_t ODOMETRY_DIRECTION_STOPPED = 0;
constexpr int8_t ODOMETRY_DIRECTION_FORWARD = 1;
constexpr int8_t ODOMETRY_DIRECTION_REVERSE = -1;

// ----------------------- PID para el pasillo ------------------------

// S1 y S2: lado izquierdo. S3: frente. S4 y S5: lado derecho.
// Error = (S1*W1 + S2*W2) - (S4*W4 + S5*W5).
constexpr float SENSOR_WEIGHT_S1 = 1.0f;
constexpr float SENSOR_WEIGHT_S2 = 1.0f;
constexpr float SENSOR_WEIGHT_S4 = 1.0f;
constexpr float SENSOR_WEIGHT_S5 = 1.0f;

constexpr float CORRIDOR_KP = 0.12f;
constexpr float CORRIDOR_KI = 0.0015f;
constexpr float CORRIDOR_KD = 0.006f;
constexpr float CORRIDOR_INTEGRAL_LIMIT_DEGREES = 8.0f;
constexpr float CORRIDOR_DERIVATIVE_FILTER = 0.25f;

// Cambiar a 1 si el PID del pasillo gira al lado contrario.
constexpr int8_t CORRIDOR_SERVO_DIRECTION = -1;

constexpr uint16_t MAX_LATERAL_DISTANCE_MM = 1500;
constexpr uint16_t FRONT_CORNER_START_MM = 600;
constexpr uint16_t FRONT_CORNER_CRITICAL_MM = 180;
constexpr float CORNER_KP_MULTIPLIER = 1.8f;

// ---------------------- Direccion por OpenMV ------------------------

constexpr int OPENMV_X_MIN = -100;
constexpr int OPENMV_X_MAX = 100;

constexpr int LOW_ROI_CONE_FAR_Y = 130;
constexpr int LOW_ROI_CONE_NEAR_Y = 200;
constexpr int LOW_ROI_CONE_FAR_HALF_WIDTH = 30;
constexpr int LOW_ROI_CONE_NEAR_HALF_WIDTH = 65;

constexpr int HIGH_ROI_STEERING_GAIN_PERCENT = 200;
constexpr int LOW_ROI_EVASION_GAIN_PERCENT = 300;

// Cambiar a -1 si la direccion por camara gira al lado contrario.
constexpr int8_t OPENMV_SERVO_DIRECTION = 1;

// ------------------- Entrega camara -> ultrasonicos -----------------

// Despues de alcanzar ROI_LOW, el ID del pilar queda enclavado. La camara
// conserva el control hasta que los sensores del lado por el que se rebasa
// confirman el pilar. El bloqueo se conserva hasta que ese lado se despeja,
// para impedir que otro pilar mueva el servo antes de tiempo.
//
// Verde: el robot pasa por la izquierda y el pilar queda a su derecha (S4/S5).
// Rojo: el robot pasa por la derecha y el pilar queda a su izquierda (S1/S2).
constexpr uint16_t PILLAR_SIDE_DETECT_MM = 300;
constexpr uint16_t PILLAR_SIDE_CLEAR_MM = 360;
constexpr uint8_t PILLAR_SIDE_CONFIRM_SAMPLES = 2;

// Aunque el costado ya parezca libre, conserva el ID actual durante este
// tiempo continuo. Evita que una linea de esquina o el siguiente pilar cambien
// el objetivo inmediatamente despues del rebase.
constexpr unsigned long PILLAR_POST_CLEAR_HOLD_MS =100;    /////despues del pasarlo

// Al quedar el pilar junto al robot se deja de perseguir su ultima coordenada
// de camara, pero se conserva un giro moderado para terminar de rodearlo.
constexpr int PILLAR_WRAP_CORRECTION_DEGREES = 20;
constexpr uint8_t PILLAR_WRAP_SPEED_PERCENT = 35;

// El rodeo termina cuando los ultrasonicos de ese costado ven libre. Si lo
// que tienen enfrente es una pared y no el pilar, nunca ven libre: sin
// este tope el robot se queda girando contra la pared hasta chocar.
constexpr unsigned long PILLAR_WRAP_MAX_MS = 900;

// Con la pared de frente (S3 por debajo de FRONT_GUARD_ACTIVATE_MM) el
// pilar esta pegado a esa pared y rodearlo exige una maniobra mas larga:
// cortar a los 900 ms deja al robot atravesado. Mismo criterio que ya
// aplican FRONT_GUARD_HANDOFF_TIMEOUT_MS y
// FRONT_GUARD_LOCK_RELEASE_TIMEOUT_MS.
//
// El escape de pared de S3 a 15 cm sigue teniendo prioridad sobre esto,
// asi que alargar el rodeo no quita la proteccion contra el choque.
constexpr unsigned long FRONT_GUARD_WRAP_MAX_MS = 1600;

// Cambio de pilar (el caso verde -> rojo).
//
// Mientras un pilar esta enclavado, las tramas de OTRO color se ignoran
// por completo, pero el motor sigue dirigiendo hacia las ULTIMAS
// coordenadas del enclavado. Si el verde ya se rebaso y la camara solo ve
// rojo, el robot sigue girando hacia donde estaba el verde y se mete en la
// pared. Cuando el enclavado lleva este tiempo sin verse y la camara
// insiste con otro, se suelta el bloqueo para que el nuevo tome el mando.
//
// Nunca se abandona un rebase en curso: si el pilar enclavado sigue a la
// vista, su marca de tiempo se refresca y el cambio no se dispara.
constexpr unsigned long PILLAR_SWITCH_STALE_MS = 220;
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
